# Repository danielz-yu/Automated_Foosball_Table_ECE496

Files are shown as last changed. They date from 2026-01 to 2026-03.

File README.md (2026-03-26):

# Vision-Guided Automated Foosball Opponent

**ECE496Y Capstone Design Project | University of Toronto**
<br>
**Team 2025162**

An autonomous foosball opponent system that combines real-time computer vision, mechanical actuation, and control systems to create an engaging single-player foosball experience. The system uses overhead camera tracking to detect ball position and trajectory, then controls motorized rods to intercept and kick the ball with human-competitive reaction times.

**Key Features:**
- Real-time Vision Tracking: 100 FPS global shutter camera with OpenCV-based ball and player detection
- Dual-Motor Control: Independent rotational (kick) and translational (positioning) motors per rod
- Sub-200ms Reaction Time: Faster than average human reaction time of 250ms
- Non-Permanent Installation: Removable attachment system that preserves original table

✅ **Status:** Completed!
<br>
🎯 **Target Demo:** March 25-28, 2026
<br>
💵 **Budget:** [~$2.5k](https://github.com/danielz-yu/Automated_Foosball_Table_ECE496/blob/main/deliverables/Budget%20Estimate%20%7C%20Team%202025162.pdf)
<br>
🗓️ **Timeline:** Sept. 2025 - Mar. 2026

<div align="center">
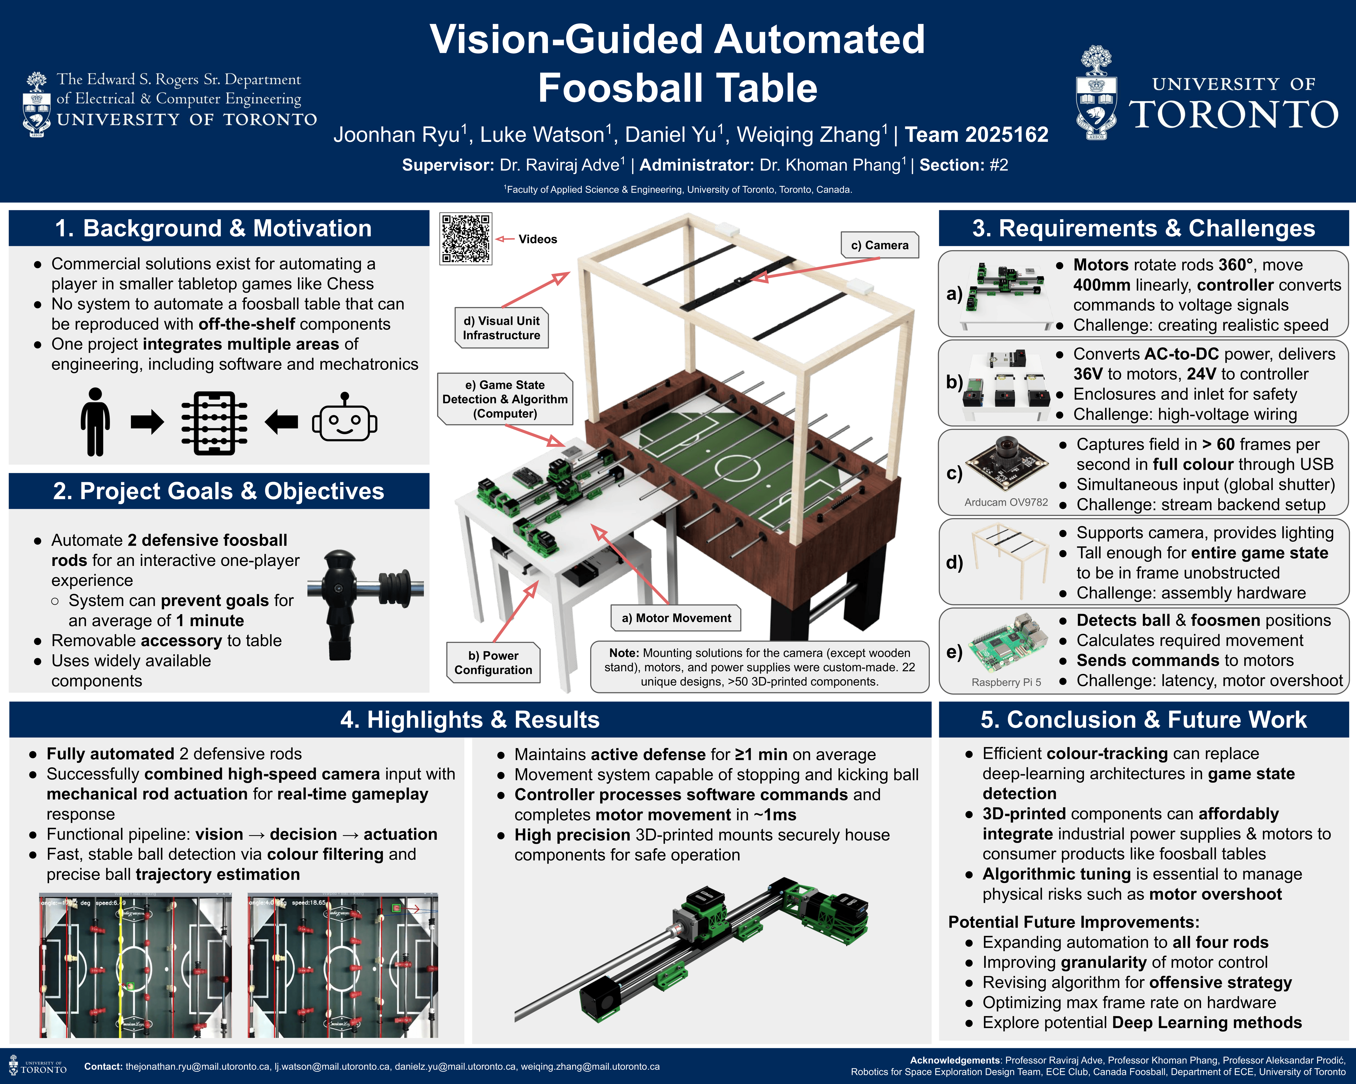
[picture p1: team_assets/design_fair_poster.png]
Design Fair Poster
    
</div>

<br>

<div align="center">
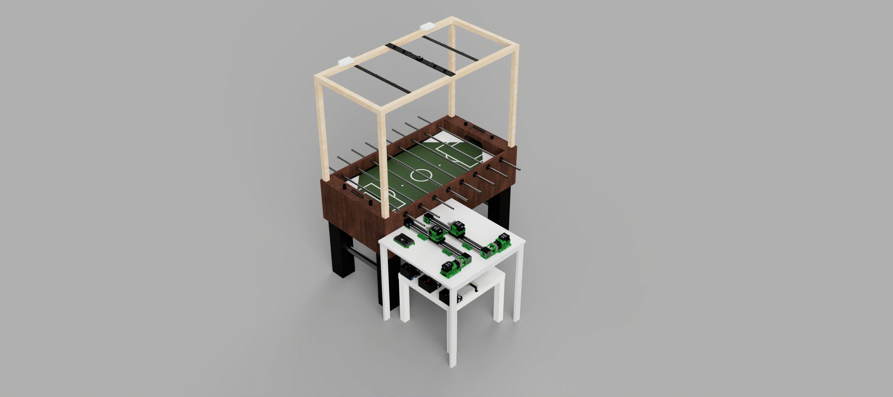
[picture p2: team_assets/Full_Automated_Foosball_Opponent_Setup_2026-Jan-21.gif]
Full Automated Foosball Table Gif (Jan. 2026)
    
</div>

## 🎯 Project Goals
- Develop defensive gameplay capable of defending for 1+ minute against untrained players
- Achieve ball control at speeds up to 1 m/s
- Demonstrate practical integration of ECE concepts: computer vision, embedded systems, control theory, and mechatronics
- Create a reproducible design for future educational use

## 🏗️ System Architecture
**Vision System:**
- Camera: ArduCam OV9782 (100 FPS, global shutter, USB interface)
- Processing: Raspberry Pi 5 (16GB RAM)
- Mounting: Custom wooden stand with 3D-printed camera holder

**Mechatronics:**
- Rotational Motors: NEMA 23 Integrated Easy Servo (90W, 3000 RPM, 0.3 Nm)
- Translational Motors: NEMA 23 Integrated Easy Servo (180W, 3000 RPM, 0.6 Nm)
- Linear Actuators: HPVB45 Belt-driven system (400mm travel)
- Controller: Teknic ClearCore motor controller
- Custom Parts: 3D-printed couplers, mounts, and brackets

**Power Distribution:**
- Translational Servos: 2× MEAN WELL LRS-350-36
- Rotational Servos: 1× MEAN WELL LRS-600-36
- Controller: MEAN WELL LRS-350-24
- Raspberry Pi: 27W USB-C adapter

**Software Stack:**
- Language: Python 3.12
- Vision Processing: OpenCV (colour filtering, ArUco marker detection)
- Control: Teknic ClearCore API
- Communication: USB serial (Raspberry Pi ↔ ClearCore)

## 👥 Team Members
**Students:**
- Joonhan Ryu
- Luke Watson
- Daniel Yu
- Weiqing Zhang

**Supervisor:** Dr. Raviraj Adve
<br>
**Administrator:** Dr. Khoman Phang

## 📄 License
This project is developed as part of ECE496 at the University of Toronto. The design is open-source for educational purposes.

## 🙏 Acknowledgments
- Professor Adve, Professor Phang, Professor Prodić
- The Edward S. Rogers Sr. Department of Electrical & Computer Engineering, University of Toronto
- Robotics for Space Exploration Design Team
- ECE Club
- Canada Foosball

#
<div align="center">
    <a href="https://www.ece.utoronto.ca/">
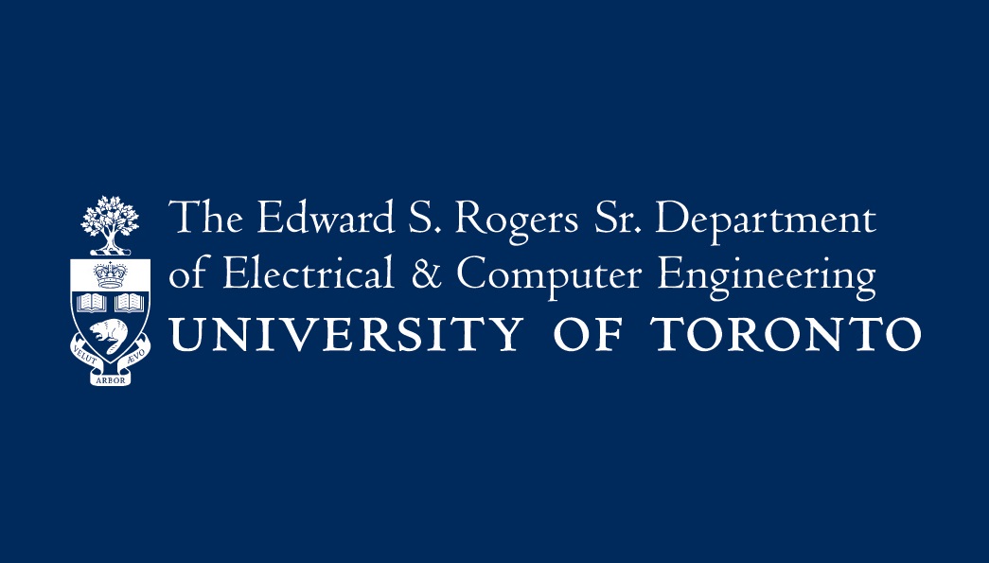
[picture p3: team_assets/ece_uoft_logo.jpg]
UofT ECE Logo
        
    </a>
</div>

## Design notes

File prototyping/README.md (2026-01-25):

# Prototyping Folder
This prototyping folder is used for initial prototyping of our ECE496 capstone project split into the Project Proposal and Project Design phases.

# Ball Tracking Software Environment Setup
1. Ensure your Python version is set to 3.12 (other versions have not been tested but it may work just the same).
2. `python -m venv <insert name of venv here>`
3. `.\<name of venv>\Scripts\Activate.ps1` if you are using PowerShell.
4. `pip install numpy==2.3.0 opencv-python==4.11.0.86`

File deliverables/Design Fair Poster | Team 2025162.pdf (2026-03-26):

- Efficient colour-tracking can replace deep-learning architectures in game state detection
- 3D-printed components can affordably integrate industrial power supplies & motors to consumer products like foosball tables
- Algorithmic tuning is essential to manage physical risks such as motor overshoot

Potential Future Improvements:
- Expanding automation to all four rods
- Improving granularity of motor control
- Revising algorithm for offensive strategy
- Optimizing max frame rate on hardware
- Explore potential Deep Learning methods

# Vision-Guided Automated Foosball Table

### Joonhan Ryu¹ , Luke Watson

1

### , Daniel Yu

1

### , Weiqing Zhang

1

### | Team 2025162

1Faculty of Applied Science & Engineering, University of Toronto, Toronto, Canada.

Supervisor: Dr. Raviraj Adve

1
| Administrator: Dr. Khoman Phang

1
| Section: #2

## 1. Background & Motivation

## 2. Project Goals & Objectives

## 3. Requirements & Challenges

4. Highlights & Results | 5. Conclusion & Future Work

a)

- Commercial solutions exist for automating a player in smaller tabletop games like Chess
- No system to automate a foosball table that can be reproduced with off-the-shelf components
- One project integrates multiple areas of engineering, including software and mechatronics
b) Power
Configuration
c) Camera
d) Visual Unit
Infrastructure
e) Game State
Detection & Algorithm
(Computer)

Acknowledgements: Professor Raviraj Adve, Professor Khoman Phang, Professor Aleksandar Prodić, Robotics for Space Exploration Design Team, ECE Club, Canada Foosball, Department of ECE, University of Toronto

Videos

b)

a) Motor Movement
- Captures field in > 60 frames per second in full colour through USB
- Simultaneous input (global shutter)
- Challenge: stream backend setup
- Supports camera, provides lighting
- Tall enough for entire game state to be in frame unobstructed
- Challenge: assembly hardware
- Detects ball & foosmen positions
- Calculates required movement
- Sends commands to motors
- Challenge: latency, motor overshoot

Note: Mounting solutions for the camera (except wooden stand), motors, and power supplies were custom-made. 22 unique designs, >50 3D-printed components.

- Automate 2 defensive foosball rods for an interactive one-player experience
- System can prevent goals for an average of 1 minute
- Removable accessory to table
- Uses widely available
components
- Fully automated 2 defensive rods
- Successfully combined high-speed camera input with mechanical rod actuation for real-time gameplay response
- Functional pipeline: vision → decision → actuation
- Fast, stable ball detection via colour filtering and precise ball trajectory estimation

c)

d)

e)

- Maintains active defense for ≥1 min on average
- Movement system capable of stopping and kicking ball
- Controller processes software commands and completes motor movement in ~1ms
- High precision 3D-printed mounts securely house components for safe operation
- Motors rotate rods 360°, move 400mm linearly, controller converts commands to voltage signals
- Challenge: creating realistic speed

Raspberry Pi 5

Arducam OV9782

- Converts AC-to-DC power, delivers 36V to motors, 24V to controller
- Enclosures and inlet for safety
- Challenge: high-voltage wiring

Contact: thejonathan.ryu@mail.utoronto.ca, lj.watson@mail.utoronto.ca, danielz.yu@mail.utoronto.ca, weiqing.zhang@mail.utoronto.ca

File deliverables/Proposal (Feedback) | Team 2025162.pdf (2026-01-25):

### UNIVERSITY OF TORONTO

ECE496 CAPSTONE PROPOSAL

TEAM 2025162, SECTION 2

# Vision-Guided Automated Foosball Opponent

Authors

Joonhan Ryu
thejonathan.ryu@mail.utoronto.ca

Luke Watson
lj.watson@mail.utoronto.ca

Daniel Yu
danielz.yu@mail.utoronto.ca

Weiqing Zhang
weiqing.zhang@mail.utoronto.ca

Supervisor

Dr. Raviraj ADVE

Administrator

Dr. Khoman PHANG

October 1st, 2025

## Executive Summary

This project seeks to develop a vision-guided automatic foosball opponent, combining real-time computerized game state tracking and mechanical actuation of rods.

It will involve multiple concepts of Electrical and Computer Engineering, providing a diverse coverage of key concepts learned by the team throughout their undergraduate education. It is important in practice as computerized opponents in other popular games such as chess or go have gained recognition, but a game with a mechanical side such as foosball has not yet been implemented in a reproducible way with off-the-shelf components and techniques.

The final product will be a removable attachment to a full-size foosball table (standard table dimensions used in professional foosball competitions) which can perform defensive gameplay for at least two rods for one side, with a reaction time around 0.2 seconds; however, effective offensive gameplay is in additional plans if the above objectives are completed.

For effective tracking, a combination of simple computer vision techniques such as color filtering or edge detection, taking full advantage of available visual input devices able to take fully synchronized frames at above 60 FPS while allowing calculation to keep up with framerate, will be used. A universal interface will allow viewing of game state and visually represented calculations while in implementation different hardware will be used to focus on control only. Off-the-shelf motors under $500 for each member of the team providing at least 1.158Nm of torque and 1000RPM of speed will ensure realistic reactions in gameplay, with one set for rotational movement and another for translational movement of the rods.

This project seeks to transform this recreational activity to a demonstration of Electrical and Computer Engineering concepts and allow players of all calibre to engage and practice in an effective single-player mode, gathering interest in both the engineering and the game.

## Contents

## 1.0 Introduction

Foosball has long been a popular tabletop game enjoyed around the world in family homes, offices, recreational centres, and professional settings. The appeal lies in its fast-paced simulated soccer gameplay and its unique blend of strategy with luck. Traditionally, this tabletop game has always been played between humans, with the winner determined on the basis of their reflexes, positioning, and ball control. However, with the evolution of intelligent robotic systems, it has become increasingly feasible to bring autonomy into various highly interactive games such as foosball.

Autonomous opponents in the game of foosball would highlight multiple levels of robotics research challenges, including but not limited to decision-making, visual perception of fast-moving objects, and prediction-based actuation. Additionally, the development of an automated foosball opponent serves both educational and research value as a fully integrated control system with the foosball table would demonstrate applied robotics concepts in real time; furthering the field of human-machine interfaces and interactive robotics.

## 2.0 Background and Motivation

Foosball is a tabletop game in which two or more players simulate soccer by controlling small plastic players mounted on metal rods, able to move in a linear and rotational fashion. It joins the ranks of other casual activities, such as darts and chess, with similar opportunity for competitive progression. In recent years, this category of games has seen a trend of projects that re-imagine how they can be played using technology. For example, a viral video by Mark Rober demonstrates a dart board that automatically moves to intercept the player’s dart through robotics and real-time tracking [1]. Foosball is an ideal candidate for this kind of experiment: its base functions are simple and accessible, yet the challenge of automation involves an interesting mix of hardware and software development, ultimately resulting in an engaging platform to demonstrate concepts in engineering.

There exists some commercial products which focus on automation of games, such as Chessnut, a chessboard that moves the pieces by itself. However, for larger scale games such projects are usually limited to student projects or hobbyists due to their size. Foosball automation is a concept that has been explored to a limited extent, mostly in post-secondary settings. Some studies have focused on individual aspects of the system, such as a paper from Eindhoven University that discusses methods of ball tracking in a ”semi-automated foosball table” [2]. A few more complete projects have been produced by student groups over the years, including one from California Polytechnic University, in which a system with full movement for four rods was built [3]. Each has their own strengths and limitations. For example, this group was able to implement a sophisticated mechanical setup but was unable to finish a working vision system. Projects seem to fall into two categories: a lack of proper funding results in an underpowered system, or the use of expensive sponsored components results in a successful system limited in its reproducibility. Our project aims to be built from scratch using entirely off-the-shelf components, while achieving a system that performs well and is easily replicated.

The main reason we chose this project is because it presents an opportunity to build something practical that integrates skills from multiple fields of Electrical and Computer Engineering in a unified system. Automation of a football table requires knowledge of power, embedded systems, real-time communication, computer vision, and algorithm design. The design process will involve the development of these individual components as well as how they interface together. Ideally, other students will also be able to interact with our design, and future groups can take inspiration from and build on our accessible implementation process, lowering the barrier to entry in terms of funding and complexity. Ultimately, this project highlights how familiar games can platform educational concepts and engineering tools.

## 3.0 Problem Statement

Traditional foosball tables rely entirely on human players to control the rods and react to the ball’s movement. While foosball is a popular recreational activity, current tables offer no digital aspect, let alone an automated opponent that can match human reaction times and conduct strategic play, and may also be difficult for beginners to get into the game, caused by the differences in player skill levels. This limits the ability to use foosball as a platform for exploring human-machine interaction and also forces foosball to an often unbalanced two-people play.

Therefore, there is a need for a vision-guided foosball opponent that integrates real-time ball tracking and mechanical actuation of rods. Such a system would not only provide an engaging opponent for casual play, but also provide a unique opportunity to showcase engineering skills, including computer vision, embedded systems, and software-hardware integration, in a recreational setting that is both accessible and engaging to a wide audience.

To achieve this, we will start working on the control of two rods that can coordinate with each other, potentially implementing all four rods on a standard sized foosball table. The development will be divided into four subsystems: the visual unit, calculation unit, control unit, and the power unit, with each team member primarily responsible for one area.

## 4.0 Project Goal

The goal of this project is to develop a control system that automates one side of a foosball table’s rods, allowing for primarily reactive but potentially active play, controlling the ball at upwards of 1m/s and defending up to one minute of continuous play.

## 5.0 System Requirements Specification

### 5.1 Vision and Strategy

Table 1. Requirements, constraints, and objectives of the vision/strategy portion.
ID | Specification | Description
1 | Input device framerate > 60 FPS. | Objective: Higher is better.
2 | Input device must detect in full color. | Requirement: For more effective detection of objects by color.
3 | Calculation of required rod movement including lateral position and kick trigger for all 1 motorized rods in < inputframerate seconds. | Requirement: Each frame should have its own calculation to update the rod position with the latest information.
4 | Input device must take all areas of frame simultaneously. | Requirement: Each part of the frame should be equally accurate to the time the information was processed.
5 | Software must have a visual ”debug” mode which shows detections, activations, and ball motion state. | Requirement: The automated system’s vision processing status should have a visible mode for finetuning purposes that can be switched off for optimization when running in normal use.
6 | Device must be able to detect whole ball and player positions in each frame | Requirement: Position of ball is required for defensive actions, and player positions for strategic offensive actions.
7 | Input device must not be visually obstructed on the way to the ball or the players | Requirement: Cannot see game state if game state is visually obstructed.
8 | Input device must connect using a universal interface (e.g. USB). | Constraint: Control hardware will change between simulation and action, and a common interface should be used for the software to use the same structure of input.

### 5.2 Mechatronics

Table 2. Requirements, constraints, and objectives of the mechatronics portion.
ID | Specification | Description
9 | Motor Input Power: Minimum 24VDC and 7.5A | Requirement: Power supply must meet this specification. See Appendix B for further details.
10 | Components Price: Does not exceed an investment of $500 from each group member, we must assume there will not be any re-reimbursements. | Constraint: Total cost cannot exceed this amount, therefore we will not acquire top-of-the-line components.
11 | Construction: System does not make permanent modifications to the foosball table, rather acts as an accessory that can be removed. | Objective: The table will be modified if needed.
12 | Rotational Motor Specifications: The motor must rotate at least 120 degrees, and output peak torque and speed of 1.158Nm and 1000RPM. | Requirement: This is for realistic gameplay. See Appendix C for detailed calculations.
13 | Translational Motor Specifications: The motor must support up to 2kg in translational movement, rotate 360 degrees, and output a peak torque and speed of at least 1.2Nm and 500RPM. | Requirement: This is for realistic gameplay. See Appendix D for detailed calculations.
14 | Linear Guide Rail: Minimum travel length must be at least 400mm. | Requirement: Based off our own measurements, the travel distance of the foosball rods fall under 400mm of travel distance, however, rods with shorter movements can use correspondingly shorter guide rails.
15 | Reaction Time: The reaction time of the motor together should average at 0.2s. | Objective: An average human reaction time is around 0.25s, therefore, the estimated motor reaction time needs to be faster to account for the computer processing time for our visual perception setup.
16 | Automated Rods: Two or more rods. | Objective: Setup will have 2 or more automated rods
17 | Defensive Ability: One or more minutes. | Objective: The system will be able to defend against a goal for at least one minute against an untrained player.
18 | Does Not Obstruct Human Side: No interference. | Requirement: Does not interfere with the opposing side of the foosball table or the abilities of the human to play..

Table 1 shows the systems requirements for the vision and strategy aspects of our design requirements for the foosball while Table 2 shows the systems requirements for the mechatronics side.

## 6.0 System Block Diagram

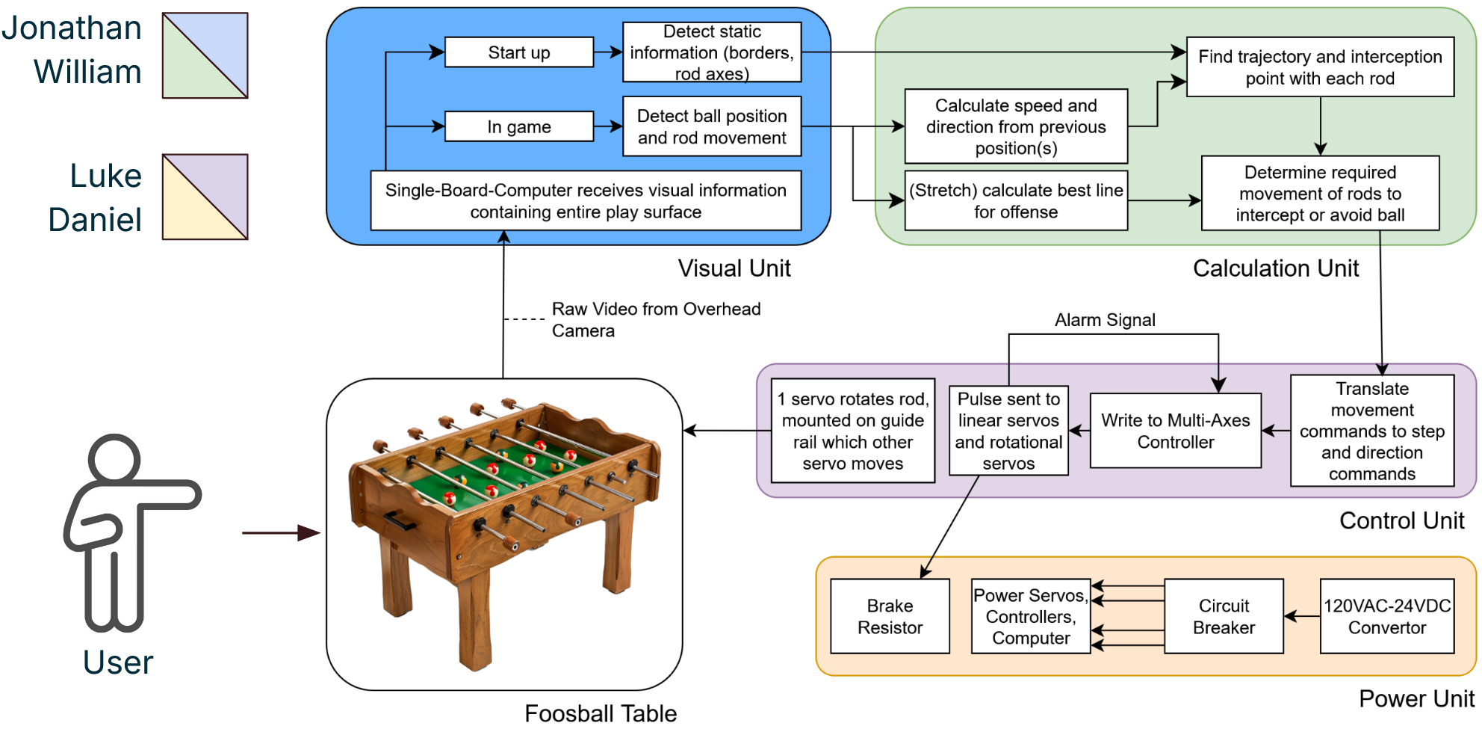
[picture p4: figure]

Figure 1. Block diagram of the automated foosball opponent system.

Figure 1 shows the overall block diagram for our system, separated into five individual units. The labels on the left denote the initial separation of responsibilities of the group members.

Starting with the foosball table, which the user interacts with on one side, an overhead video camera feeds raw footage into the Visual Unit. This unit is responsible for processing this information and generating positioning for the elements of the game, including the field boundaries, rod axes, and most importantly ball movement. This data is fed into the Calculation Unit, a micro-controller that will determine the required positioning of the automated rods to intercept the ball. Finally, the Control Unit translates this into commands output to the motors, which move and rotate the rods. Behind this flow, the Power Unit is necessary for supplying all of these different elements with sufficient power, including the motors and controller. All of these units must work together within a short time-frame to achieve real-time play.

## 7.0 Risk Assessment

Our team has identified four risks which could negatively affect the outcome of our project.

### 7.1 Uneven and Inconsistent Lighting

- During some experiments with the prototype, it was noted that edges were not as visible or colors may differ depending on lighting angle and intensity, as well as the general temperature of any light source.
- These effects may impact detection of the ball and rod, unable to either capture the full area (thus making the detected position off-center) or not capture at all, which makes accurate calculations at the desired framerate impossible.

- This is likely to happen given the variable amounts of outside sunlight and the fluctuation in artificial lighting depending on setting. To mitigate this problem, a method to evenly light the table (not affected by the shape of any light source, and thus most likely diffused) in a manner not invasive to gameplay is necessary.

### 7.2 Insufficient Accuracy of Rod Detection

- One concern about any potential methods of vision detection is that the rods may be partially or wholly undetected. The majority of cases are caused by the aforementioned lighting issue which can be mitigated, and thus this is not a major problem for the defensive case (where position of defense rods are known and there is the width of each foos-figure as a margin of error in interception).
- However, in the offensive case, the angle of attack (and the consequential line taken by the ball, in comparison with the one which minimizes interceptions) will be dramatically altered by small differences in where the ball is struck.
- While this is likely to happen, coinciding with the lighting issue, since offensive play is a stretch goal on its own, it is not highly urgent. This can be mitigated by creating backup methods of lateral rod position detection for non-motorized rods, or at the very least accurate estimates if the disparity is only a few frames long.

### 7.3 Motor Power is Insufficient

- A key component in the functionality of the automated system is the ability of the selected motors to provide enough power to rotate and move the rods so that the ball can be intercepted and kicked. The probability this will occur is low for the motors responsible for rotation, as the selected motors were above the calculated requirements. The motors guiding the linear system, however, are more at risk due to the more complex setup and weight they have to move.
- The consequence of one of the motors failing in this regard would be a limitation on the overall system to respond to a user’s inputs in a realistic way. The game would not be playable as the rods would likely miss interception, being too slow to react, or not able to kick the ball with enough force to move it.
- The root cause of this risk is both the motors themselves and our chosen setup. If either motor is too weak, it can be replaced with a more powerful version. However, this can only go so far in our goal to build an inexpensive and reproducible system. In addition, the stronger and heavier the rotational motor is the more weight the linear motor has to move. Therefore, the specifications can be modified to use a less powerful but lighter motor for rotational movement. This means kicking the ball with less force, but the system would at least be able to intercept it. Ultimately, if no combination of motors is able to both intercept the ball and deliver enough force to move it, the scope of the project must then be restricted to only gameplay in which the user plays at a slow speed. This would not be realistic gameplay, but would still allow for a demonstration of potential capabilities.

### 7.4 Processing Time is Too Slow

- Given the previous risk is not an issue and the motors can indeed react with enough speed and force, another possibility is the commands simply cannot be generated in time to feed to the motors. This involves the processing of the visual data into ideal movements to intercept the ball. We have attempted to mitigate this risk by acquiring an extremely fast computer to perform the necessary calculations in real-time. However, there is still a smaller but present chance that the latency of each different element adds up to a point where the signals are not being sent to the motors in time.
- The result of processing time being too slow is again a lack of realistic play. However, this time it is not realistic to simply replace components to improve the speed of this system.
- The scope of the prediction algorithm can be simplified to speed up processing if required. Ultimately it can be reduced to simply moving the rod to intercept the ball. Similarly to the previous risk, if there is no feasible way to achieve realistic processing time, slow gameplay can be enforced.

## 8.0 Conclusion

In summary, the development of an automated foosball opponent addresses the absence of digital and interactive features in traditional foosball tables. By integrating real-time computer vision, mechatronic controls, and software–hardware coordination, this project will transform a familiar recreational activity into an engaging platform for both entertainment and engineering demonstration, not only for advanced players, but also beginners interested in the game.

On top of a new form of recreational play, the project provides a meaningful opportunity to showcase engineering skills across software and hardware domains, including control systems, computer vision, and embedded systems. The successful completion of this project will create a final product that is both accessible to a wide audience and valuable as a showcase of engineering in a recreational field.

## Appendix

## A Gantt Chart

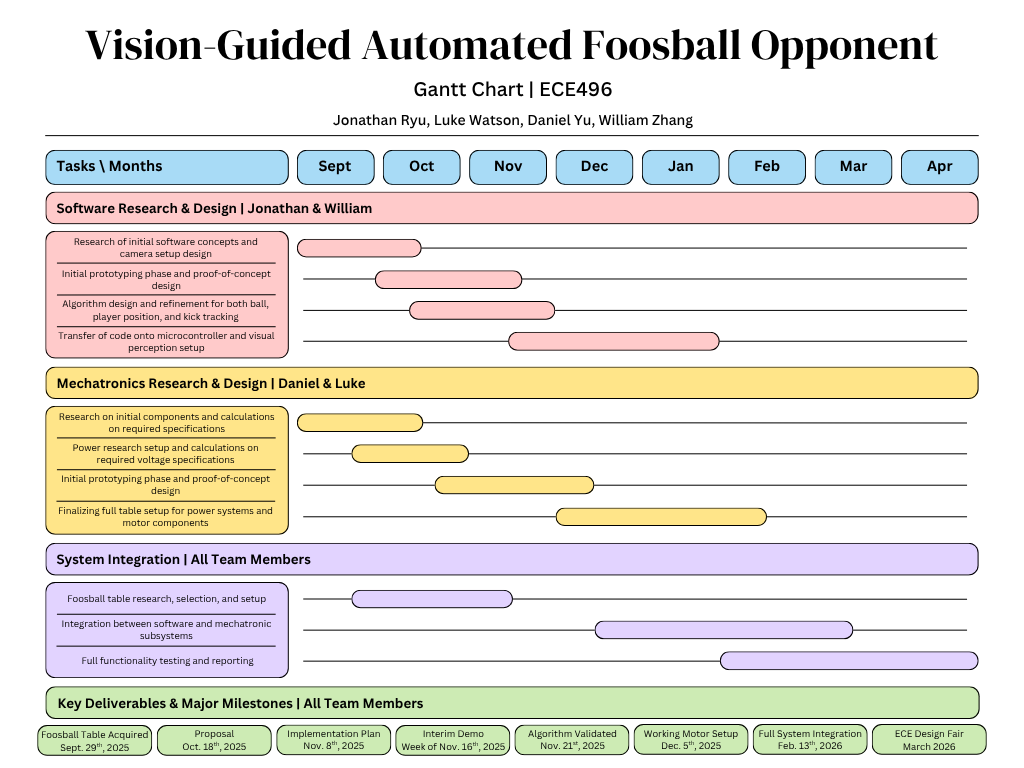
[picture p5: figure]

Figure 2. Gantt chart timeline for the 2025-2026 academic year.

Figure 2 above shows the projected timeline of tasks, key deliverables, and major milestones displayed in a Gantt chart.

## B Selected Motor Power Requirements

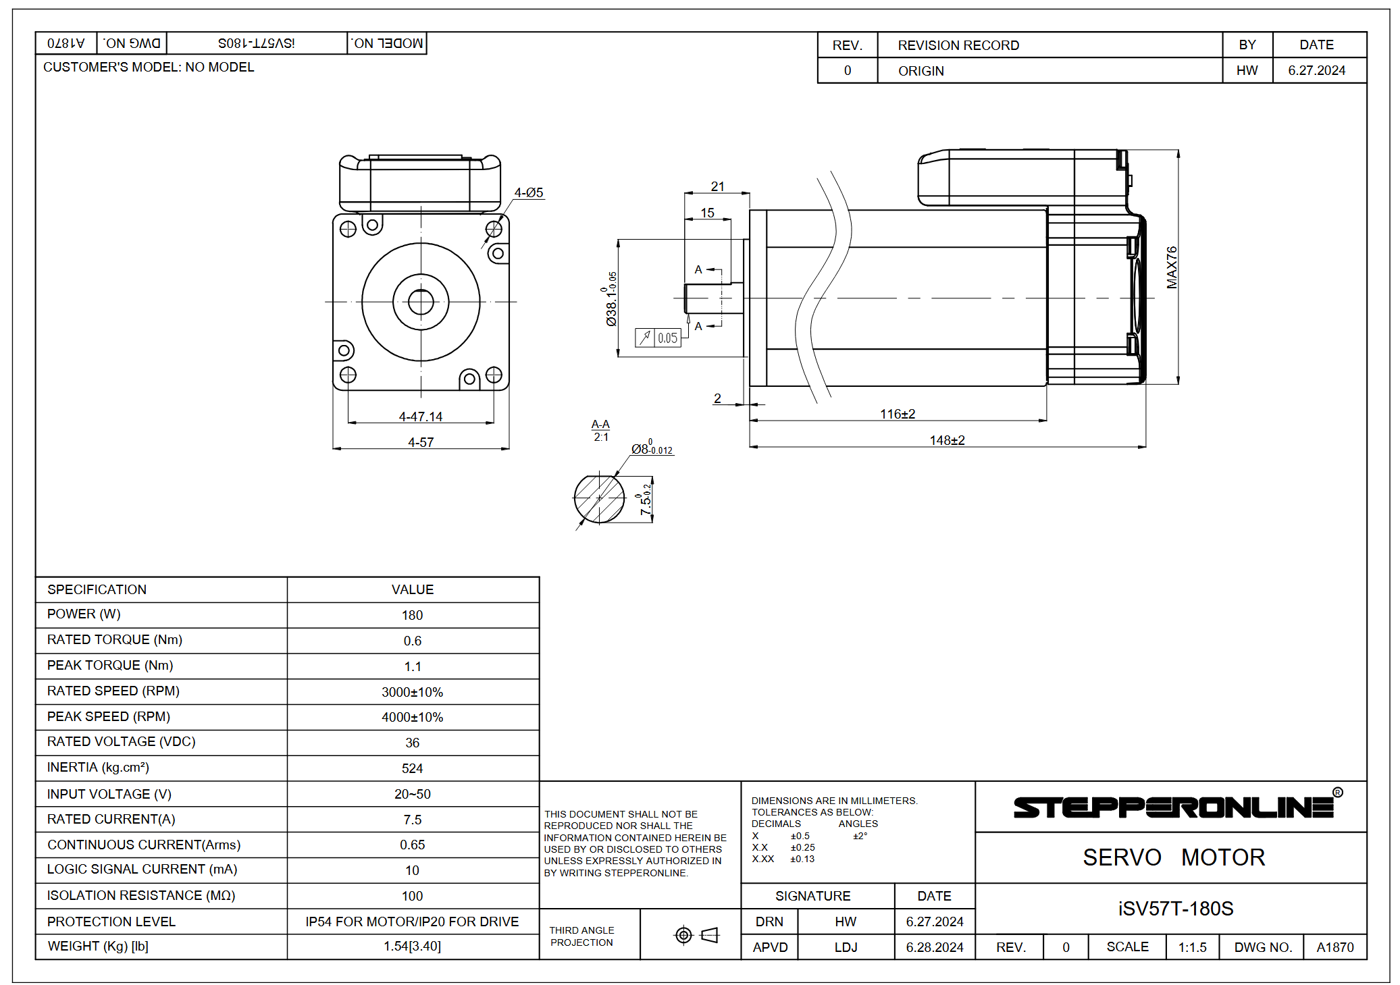
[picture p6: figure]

Figure 3. Selected motor data sheet.

## C Rotational Motor Specification Calculations

C.1 Speed

Assume the tangential speed of the foosman (attached to the rod) directly translates to the speed of the ball.

Most component specifications for speed are given in Rotations Per Minute (RPM). To derive this from speed, this formula can be used:

RPM =

ω · 60
2π

where ω is the angular velocity given by ω =

v
r

The radius in this case is the distance from the center of the rod to the foot of the foosmen, since that is the point of contact with the ball.

The height of the center of the rod from the playing field is about 3”, or 76 mm. On a professional table, the foosmen have a clearance of about 6.35 mm. In practice this value can be much higher, and since a higher clearance will give a smaller radius, and therefore larger RPM, take a higher bound of 16 mm. Therefore we can assume the radius to be approximately 60 mm. Now we can graph this equation to see what RPM will be required for desired speeds.

y =

v · 60
2π · 0.06

Thus to acheive a speed of 6m/s, around 1000 RPM is required.

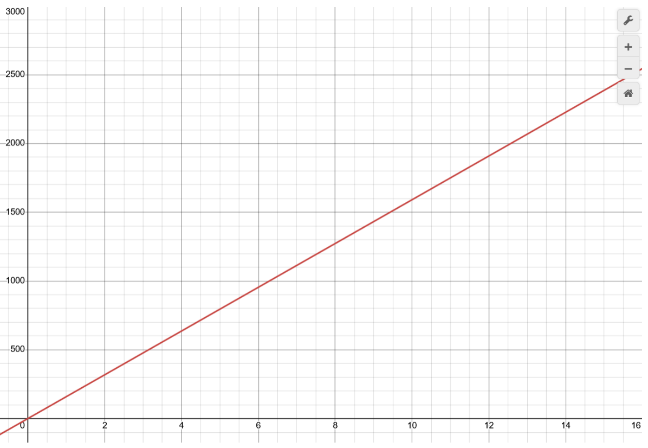
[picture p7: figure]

Figure 4. Speed to RPM.

C.2 Torque

The torque required to accelerate the rod to a desired velocity will be calculated using the formula:

τ = I · α

where I is the total inertia of the system and α is the angular acceleration.

I can be calculated as the sum of the load inertia and the motor’s rated inertia:

I = Iload + Irotor

where load inertia is the combination of inertia from the rod and from the foosmen:

Iload = Irod + If oosmen =

1
2

m · r

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
Assume the mass of the rod to be 0.7 kg¹

and the radius to be 8 mm² . This gives

Irod =

1
2

(0.7)(0.008)² = 2.24 · 10⁻⁵ kg · m

2

Since we are focusing on 2 defensive lines of play, the most foosmen a rod can have is 3, so we will use that value for N. Take a weight of 50g³
and radius of 60 mm, we get

If oosmen =

X

N

i=0

mir

2
i = N · m · r

2 = 3 · 0.05 · 0.06² = 5.4 · 10⁻⁴ kg · m

2

and subsequently

Iload = 2.24 · 10⁻⁵ + 5.4 · 10⁻⁴ = 5.625 · 10⁻⁴ kg · m

2

The reference data sheet in Appendix B shows the rotor inertia to be 524 g · cm² , giving

I = 5.265 · 10⁻⁴ + 524 · 10⁻⁷ = 5.79 · 10⁻⁴ kg · m

2

Next, to calculate angular acceleration, we first take a target speed of 6m/s and foosmen contact radius of 0.06m to calculate angular velocity:

ω =

v
r

=

6
0.06

= 100 rad/s

Time is more of a limiting factor than angle due to the fact that a servo should be able to rotate the rod a full 360 degrees, so we will use the formula

α =

ω
t

instead of α =

ω

2

2θ

Finally, with a 50ms timeframe for the motor to reach this desired speed from rest (ω0 = 0), we get

α =

ω
t

=

100
0.05

= 2000 rad/s²

Final torque is then calculated as:

τ = 5.79 · 10⁻⁴
- 2000 = 1.158 N · m

1Assuming a steel hollow rod.
2Using a typical rod with diameter of 5/8”. 3Typical weight for a non-counterbalanced foosmen.

## D Translational Motor Specification Calculations

The goal for the translational motor is to achieve realistic gameplay in a casual setting against a human opponent. We are aiming for a 1m/s translational speed with a reaction time of 0.05s⁴
. In addition, since
the translational motor needs to carry rotational motor, we can assume that it needs to carry at least 2kg of weight⁵

In order to determine the minimum required torque and speed, we first need to determine the total amount of force applied on this system using both the acceleration and force equations.

Fg = mg = 2 kg × 9.81 m
s

2 ≈ 20 N

a =

v
t

=

1

m
s
0.05 s

= 20 m
s

2

Fa = ma = 2 kg × 20 m
s

2 = 40 N

Ft = Fg + Fa = 20 N + 40 N = 60 N

From our calculations above, we need to exert at least 40 Newtons of force. To determine the corresponding peak torque and speed requirements, we can apply the torque, angular velocity, and RPM formulas below.

τ = rF sin θ = 0.02 m × 60 N = 1.2 N·m

The sine theta angle above is 90 degrees since the linear guide rail creates a constant perpendicular angle, resulting in the sine component of the torque equation to be equal to 1.

ω =

v
r

=

10 m
s
0.02 m

= 50 rad
s

The radius component in both the torque and angular velocity equations is estimated to be around 20mm from research completed on current off-the-shelf linear guide rail models.

RPM =

ω × 60
2π

=

50 × 60
2π

≈ 500RPM

Based on our calculations, the required peak torque of our motor is 1.2Nm while the speed of the motors to maintain our goal of 1m/s needs to be at least capable of 500RPM. If needed, a gearbox can be added to this system to further increase the output torque.

4Based on the same desired timeframe from standstill to full speed in Appendix C.

5
From Appendix B, the selected motor is 1.54kg in weight and so we can assume 2kg as a safe margin of error with regards to additional miscellaneous weights such as screws.

## References

[1] M. Rober. (2017, 03) Automatic bullseye, moving dartboard. Accessed: 2025-10-01. [Online]. Available: https://www.youtube.com/watch?v=MHTizZ XcUM (https://www.youtube.com/watch?v=MHTizZ_XcUM)
[2] R. Janssen, J. Best, and M. Molengraft, “Real-time ball tracking in a semi-automated foosball table,” 06 2009, pp. 128–139.
[3] J. D. Gutierrez-Franco, J. Inlow, J. Graham, and L. Huang, “Automated foosball table year 1: Final project report,” California Polytechnic State University, Tech. Rep., Dec. 2013. [Online]. Available: https://digitalcommons.calpoly.edu/mesp/196

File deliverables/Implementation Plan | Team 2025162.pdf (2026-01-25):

UNIVERSITY OF TORONTO

ECE496 IMPLEMENTATION PLAN

TEAM 2025162, SECTION 2

Vision-Guided

Automated Foosball Opponent

Authors

Joonhan Ryu

thejonathan.ryu@mail.utoronto.ca

Luke Watson

lj.watson@mail.utoronto.ca

Daniel Yu

danielz.yu@mail.utoronto.ca

Weiqing Zhang

weiqing.zhang@mail.utoronto.ca

Supervisor

Dr. Raviraj ADVE

Administrator

Dr. Khoman PHANG

November 8th, 2025

Table of Contents

### 1.0 Summary of Project Status and Changes

The following section provides an overview of the current project status and changes made since the Proposal.

### 1.1 Implementation Progress

The software side of the team is transitioning from a small prototype foosball table to a full-size one. A 100 FPS global shutter color USB camera (ArduCam OV9782 [1]) was acquired, satisfying all requirements for the input device in Section 4.1. A stand for the camera module was made to ensure the playing field is visible in the frame, 3D printed for the prototype, but built with wood for the full-size. The software now has a GUI to view detections of the game state and signals sent to the motors, and can detect the ball’s position using color filtering, extrapolating its trajectory to rod interception points. This runs on a newly acquired Raspberry Pi 5 [2] with the camera connected. On the mechatronics side, the chosen motor (StepperOnline iSV57T-180S [3]) was tested for both rotational and translational functionalities. To power them, we used a MEAN WELL LRS-350-36 [4] for which we self wired and 3D printed a custom enclosure. The translational motor was connected to a belt-driven linear actuator (HPVB45 [5]), whose carriage system had the rotational motor attached on it. The overall motor setup required custom 3D printed components which our team designed; this allowed for proper load and inertia testing on both motors, aligning with the calculations in Appendices D and E. A CAD model of our wooden stand, power supply, and motor setup can be seen in Appendix F.

### 1.2 Challenges Encountered

The software side assumed that real-time positions of the motorized rods would be available through an interface with the motors, making requirements for foosball rod position detection more lax (only the non-motorized side of the table would need this technique, and accuracy can be lower, as the purpose would be for strategy in offensive play with no effect on the motorized side’s ability to deflect the ball). However, this is no longer the case with the chosen motors. Thus, the importance of accurate color filtering (or alternative techniques) has been increased, for all directions and intensities of light. Another method to gather rotational positions of the rods (not visible to the camera) is needed. The mechatronics side found challenge in the coupler’s connection to the motor. Because the iSV57T180’s output shaft is milled in a D-shape, it did not fit snugly into the circular bore of the coupler, resulting in a loose connection. This issue required a lot of careful alignment and tightening to resolve. Overall, extensive calculations and research gave the team confidence on most hardware components, allowing the power supply and motor setups to be built smoothly.

### 1.3 Plans Ahead

After verifying existing functionalities of the software on the full-size foosball table following the installation of the camera and microcontroller, the software side plans to add lateral rod position detection functionality, improve stability in lighting of the frame, and explore solutions for detecting rotational rod position before installing motor control logic. The mechatronics side will be connecting and coding a Teknic ClearCore [6] motor controller to control all motors simultaneously. Furthermore, we plan to purchase an additional table to place the hardware components on the side of the foosball table for full assembly and proper testing purposes.

### 2.0 Possible Solutions and Design Alternatives

This section details alternative design solutions and elaborates on why they were rejected.

### 2.1 List of Considered Alternatives

Before finalizing our chosen design, three system-level alternatives were explored to evaluate different approaches to vision processing and ball tracking for the automated foosball opponent seen in Table 1.

Table 1. Considered system-level alternative designs and brief reasons for why they were rejected.
ID | Description | Reasoning for Rejection
A | Full-size desktop with a GPU paired with existing color camera using a deep-learning architecture to identify ball and/or player positions | Excessively costly and power-intensive for the intended application. FPS is very low [7] and rotational angle difficult to calculate.
B | Existing microcontroller paired with monochrome camera that uses purely edge-detection mechanisms to identify ball position and player states | Lacks robustness and computational capability. Also easily foiled by other debris that can make its way onto the table, since the camera cannot distinguish between colors.
C | Avoiding vision usage entirely and instead relying on lasers on the table or GPS sensor in ball to detect its position and accelerometers on all rods to determine position | Excessive hardware complexity, calibration challenges, and integration issues.

Alternative A proposes a full-size desktop-based system utilizing a GPU paired with a color camera and deep-learning models for visual recognition of the ball and players, offering potentially high accuracy at the expense of cost, power, and complexity. Alternative B considered a lightweight microcontroller solution using a monochrome camera and edge-detection algorithms to identify ball position, trading computational simplicity for limited robustness and adaptability to changing lighting conditions. Alternative C eliminated vision altogether by relying on external sensors—such as lasers, GPS-like tracking within the ball, and accelerometers on the rods—to determine position data, introducing considerable hardware complexity and calibration challenges. Each design explored a different trade-off between computational power, sensing accuracy, and integration complexity.

### 2.2 Elaboration and Comparison of Alternative A

Alternative A: Full-size desktop with a GPU paired with an existing color camera using a deep-learning architecture to identify ball and/or player positions.

This alternative explores the use of a desktop-class computer equipped with a discrete GPU to perform deep-learning–based vision inference. In theory, such a system could run convolutional neural networks (CNNs) or transformer-based detectors to recognize and track the foosball, players, and rods in real time.

The large compute headroom of a GPU would allow for high-resolution input and potentially robust object detection even under challenging lighting or occlusion conditions.

However, several key drawbacks make this option unsuitable for the intended design objectives. A full desktop introduces significant cost, size, and power consumption far exceeding the project’s constraints [8]. The setup would require multiple pieces of large hardware, and make the already tight setup space even less achievable. Deep-learning pipelines also demand substantial training data collection and model tuning to handle variations in table color, lighting, and camera placement—an impractical effort for a prototype-scale project [9]. We would have to adjust lighting in multiple locations, but moving the table for every scenario and occasion is impractical. Moreover, GPU-based inference produces unnecessary overhead for tracking a single small object, while increasing latency due to data transfer and preprocessing steps. These limitations reduce maintainability, portability, and reliability, making the system harder to demonstrate and deploy.

Comparison with Implemented Approach: In contrast, the implemented approach utilizes a Raspberry Pi 5 running optimized classical computer-vision algorithms such as color segmentation, thresholding, and ArUco marker detection. This design achieves real-time tracking using lightweight computation that fits within the Pi’s limited CPU resources [9]. The choice of traditional vision techniques provides fast inference without the need for model training, while the use of ArUco markers offers reliable and repeatable localization of player rods and ball position under varying lighting conditions.

Compared to Alternative A, the implemented system is:

- Far more cost-effective, requiring only a single-board computer and a low-cost camera rather than a GPU-equipped PC.
- More compact and portable, allowing the vision module to mount directly on or near the foosball table without external peripherals.
- Simpler to develop and maintain, as it relies on open-source computer-vision libraries (OpenCV) [10] and deterministic algorithms instead of complex neural-network pipelines.
- Lower power and quieter, with negligible heat generation and no need for active cooling.
- Sufficiently accurate for tracking purposes: while it may not match the theoretical precision of a trained CNN under perfect conditions, it achieves robust, consistent detection that meets gameplay and control requirements [9].
- Can run at a much higher frame rate (FPS) compared to deep-learning–based approaches, even powered under a GPU [7].

Overall, while Alternative A represents the most powerful computational option, its resource demands and engineering complexity make it over-engineered for the problem. The chosen Raspberry Pi–based vision system delivers an optimal balance of performance, cost, and simplicity, fulfilling all design requirements within practical constraints. It demonstrates that lightweight, well-tuned image-processing methods can achieve reliable real-time tracking without resorting to deep-learning hardware or training overhead.

### 3.0 Technical Design and Implementation

This section will discuss the entire design plan, at a high-level and further broken down into sub-modules.

### 3.1 System-Level Overview

The overall goal of the design is to transform a video feed of the foosball playing field into the movement of two rods that intercepts an incoming ball. The process flow begins with a camera positioned overhead the table to record a bird’s-eye-view of the table. The camera feed is then processed through a Raspberry Pi 5 Single Board Computer (SBC). The SBC will initially gauge the boundaries of the table and the axes corresponding to each of the rods using the existing method of ArUco markers (”synthetic square marker composed by a wide black border and an inner binary matrix which determines its identifier (id) [11]”) for perspective transformation. Color filtering techniques in OpenCV commonly found in internet guides such as
[12] are used to acquire ball and foosmen positions, through which the trajectory of the ball is calculated and points of interception are found on the rods, which then become the desired linear position for each of the rods. A stretch goal will involve a novel algorithm to calculate the angle of attack to line the ball through empty spaces of the opponent’s foosmen.

Once the rotational angle and the linear position for each of the two rods is known, the motors will be commanded to spin to meet these targets. For each rod, one motor controls a linear guide rail, using the motor’s rotation to move a platform across a belt. This platform holds the other motor, which rotates the rod through a direct attachment. The motors used are contained within integrated servos, housing a driver controlled through voltage pulses. The Teknic ClearCore will be used to manage the direct signal control, allowing use of its API to program the servos [6]. This was chosen for its speed and reliability as opposed to a microcontroller, which would also be more prone to errors in programming the timing. The SBC, motors, and controller are all powered through connection to an AC outlet. Distance is not an issue, however, as an extension cord with 6 outlets will be used to connect each power supply individually. Except for the SBC, the components use switching power supplies configured for individual DC voltage requirements.

### 3.2 System Block Diagram

Figure 1 visually illustrates the system’s modules and connections, in addition to the separation of tasks. Note that the diagram and the following explanations assume a system with 1 rod actuated. If funding can be acquired for a 2nd rod, the control unit will essentially be duplicated.

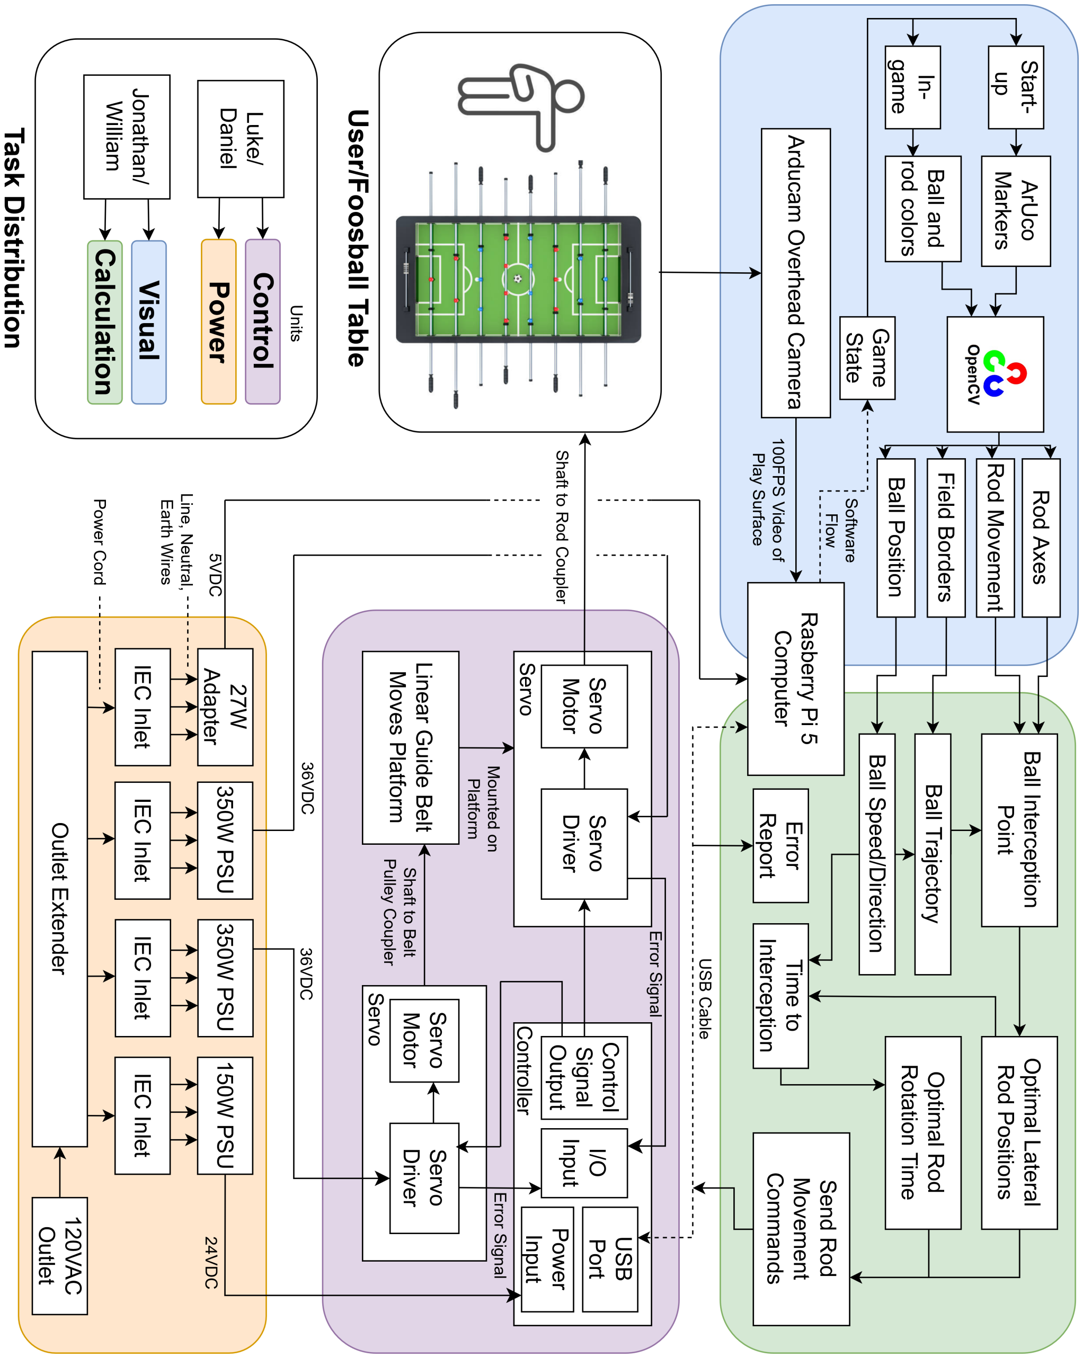
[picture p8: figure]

Figure 1. System block diagram.

### 3.3 Module Descriptions

This subsection explains the role of each connection and unit from our system block diagram.

### 3.3.1 Input/Output

The user interacts with one side of the foosball table, which has no modifications to it. The other side of the table is connected to our system and provides the rod(s) with movement response for the user to interact with.

### 3.3.2 Visual Unit

The Arducam overhead camera, after taking in a frame of the whole playing surface, sends in the frame to a Raspberry Pi 5 computer, which, on startup, detects ArUco markers on the table through the OpenCV library to gain information about the axes of the rods and border of the playing field. In game, the detection is instead for the colors of the ball and of the markers on the rods, also through OpenCV, to calculate information on the ball’s position and rods’ translational movements. This information is handed to the Calculation Unit.

### 3.3.3 Calculation Unit

Changes in the ball’s position are tracked to acquire its speed and direction, which is then extrapolated, including bounces off the playing field’s borders, then combined with rod axes locations to find interception points and thus the optimal lateral positions for each rod. Any lateral movements required to reach the positions are requested. The time taken for the ball to reach interception is also calculated using the current speed on the length of the trajectory. If that time is within the optimal rod rotation time, it requests a rotation (a ”kick”). Once a rod rotation or lateral movement is requested, it is first translated to a servo movement command using the ClearCore API which is then sent over a USB serial to ClearCore controller.

### 3.3.4 Control Unit

When the ClearCore controller receives a command to move a servo, it will translate that request to a voltage signal output to the servo’s driver. The driver also sends a signal back to the controller if a severe failure occurs, which when received by the SBC can terminate further commands. One servo is responsible for moving the belt on the linear guide rail through a pulley system, attached to the servo through a shaft coupler. The other servo is mounted on the belt’s carriage and directly connected to a rod through an additional coupler. This servo will rotate the rod and pull the rod with it when it moves linearly on the guide rail.

### 3.3.5 Power Unit

This section encompasses the components that deliver power to the rest of the system. There are four power supplies needed, two for the servos, one for the controller, and one for the SBC. It is indeed unnecessary to have individual power supplies for each unit, however this was found to be much cheaper as opposed to consolidating into one power supply. Aside from the 27W Adapter for the SBC, which resembles a laptop charging device, the rest are switching supplies with two delivering 36VDC for the servos and one 24VDC for the controller. These supplies have exposed terminals, so a 3D printed case has been used to allow for power cords to connect to inlets on the case, which are wired to the terminals inside.

### 4.0 Test and Verification

This section elaborates on methods to test and verify the design, for the requirements specified in Appendix A for the two major components: vision/strategy and mechatronics. Completed verifications are marked with (C).

### 4.1 Vision and Strategy

Table 2 details the testing methodology for the vision and strategy components of the design.

Table 2. SyRS of the vision/strategy component with testing methodologies.
ID | Specification | Verification Strategy
1 (C) | Input device framerate > 60 FPS. | REVIEW of DESIGN: Reference the datasheet of visual input unit for FPS. TEST: Verify input framerate through an application that repeats unprocessed frame input to the GUI.
2 (C) | Input device must detect in full color. | TEST: Using a webcam application that only repeats frame input to the GUI, confirm the camera is not monochrome.
3 | Calculation of required rod movement for all motorized rods in under inputframerate seconds. 1 | TEST: Add an FPS counter to the run script that displays with the debug mode (see requirement 5), where the ”FPS” is calculated by the times each processed frame is displayed.
4 (C) | Input device must take all areas of frame simultaneously. | REVIEW of DESIGN: Reference the datasheet of visual input unit. Confirm it has a global shutter.
5 (C) | Software must have a visual ”debug” mode which shows detections, activations, and ball motion state. | TEST: Confirm run with a flag on the run script which enables a live view of the camera feed in the GUI with overlays of required information, set by default to off.
6 | Device must be able to detect whole ball and player positions in each frame | TEST: In debug mode (see requirement 5), there must be one outline of the ball, and one outline per synchronization point for the lateral positions of each rod and foosmen.
7 (C) | Input device must not be visually obstructed on the way to the ball or the players | TEST: Once visual input unit and controller is installed on the foosball table, confirm there is nothing blocking view of the playing surface through an application that only repeats the frame input to the GUI.
8 (C) | Input device must connect using a universal interface (e.g. USB). | REVIEW of DESIGN: Reference the datasheet of visual input unit and confirm it utilizes a universal interface, and demonstrate above requirements while using said interface.
19 (C) | (NEW) Height of support structure must be enough to allow for selected camera to contain entire field | TEST: Confirm the entire playing surface, including borders, is visible through an application that only repeats the frame input to the GUI.
20 | (NEW) Selected computer must be able to run the software in real-time | TEST: Confirm the software can perform all functions on the chosen SBC.

### 4.2 Mechatronics

Table 3 details the testing methodology for the control and power components of the design.

Table 3. SyRS of the mechatronics component with testing methodologies.
ID | Specification | Verification Strategy
9,22 (C) | Input Power: Minimum 24VDC/7.5A for motors, 24VDC/5A for controller/ | TEST: Measure the output of the acquired power supplies before connecting them to the motors/controller.
11,18 | Construction: System does not make permanent modifications to the foosball table and does not obstruct user side. | REVIEW OF DESIGN: Confirm whether the completed system be easily removed from the table such that the original use and structure of the table is intact, and when it is present it does not obstruct unmodified side.
12 (C) | Rotational Motor Specifications: The motor must rotate at least 120 degrees, and output peak torque and speed of 1.158Nm and 1000RPM. | TEST/REVIEW OF DESIGN: The selected motors meet these specifications and have been tested to rotate the rod.
13 (C) | Translational Motor Specifications: The motor must support up to 2kg in translational movement, rotate 360 degrees, and output a peak torque and speed of at least 1.2Nm and 500RPM. | TEST/REVIEW OF DESIGN: The selected motors meet these specifications and have been tested with the target load connected to the guide rail.
14 (C) | Linear Guide Rail: The maximum travel length is 400mm (measured internally by the team). | TEST: The selected guide rail has been tested with the selected motors to achive this travel length.
15,17 | Defensive Ability: Can defend for at least 1 minute and react in 0.2s | TEST: Time the completed system to stop an untrained player from scoring a goal for at least one minute, also measuring rod movement time using the camera.
21 (C) | Controller must have 4 outputs, each with 5V step and direction signals at 300KHz per servo requirements. | REVIEW OF DESIGN: Select component exceeds these specifications.

### 5.0 References

[1] ArduCam, OV9782 Global Shutter Color Camera Module B0385, https://core-electronics.com.au/attachments/localcontent/B0385 OV9782 Global Shutter UVC Camera Datasheet 19190316e78.pdf, (https://core-electronics.com.au/attachments/localcontent/B0385_OV9782_Global_Shutter_UVC_Camera_Datasheet_19190316e78.pdf) 12 2021.
[2] Raspberry Pi. (2025, 11) Buy a raspberry pi 5. Accessed: 2025-11-05. [Online]. Available: https://www.raspberrypi.com/products/raspberry-pi-5/
[3] StepperOnline, “Nema 23 integrated easy servo motor 180w 3000rpm 0.6nm(84.98oz.in) 20-50vdc brushless dc servo motor,” Online product page, StepperOnline, accessed: 2025-11-07. [Online]. Available: https://www.omc-stepperonline.com/nema-23-integrated-easy-servo-motor-180w-3000rpm-0-6nm-84-98oz-in-20-50vdc-brushless-dc-servo-motor-isv57t-180 (https://www.omc-stepperonline.com/nema-23-integrated-easy-servo-motor-180w-3000rpm-0-6nm-84-98oz-in-20-50vdc-brushless-dc-servo-motor-isv57t-180)
[4] MEAN WELL Enterprises Co., Ltd. (2025, 09) LRS-350 Switching Power Supply Series. Accessed: 2025-11-08. [Online]. Available: https://www.meanwell.com/webapp/product/search.aspx?prod=LRS-350 (https://www.meanwell.com/webapp/product/search.aspx?prod=LRS-350)
[5] Guangzhou Hanpose 3D Technology Co., Ltd. HPVB45 Effective Travel Stroke Length 200 mm Timing Belt Linear Slide Guide Motion Module for CNC Milling Machine. Accessed: 2025-11-08. [Online]. Available: https://www.alibaba.com/product-detail/HPVB45-Effective-Travel-Stroke-Length-200mm 62368075366.html (https://www.alibaba.com/product-detail/HPVB45-Effective-Travel-Stroke-Length-200mm_62368075366.html)
[6] Teknic, Inc., ClearCore Hardware and Wiring Manual, https://teknic.com/files/downloads/clearcore user manual.pdf, (https://teknic.com/files/downloads/clearcore_user_manual.pdf) 2 2025.
[7] D. Hagens, J. Knaup, E. H. Darmstadt, and A. Weinmann. (2024, 4) Cnn-based game state detection for a foosball table. Accessed: 2025-11-05. [Online]. Available: https://arxiv.org/html/2404.05357
[8] Statista Research Department. (2025) Desktop pcs - worldwide. Accessed: 2025-11-05. [Online]. Available: https://www.statista.com/outlook/cmo/consumer-electronics/computing/desktop-pcs/worldwide (https://www.statista.com/outlook/cmo/consumer-electronics/computing/desktop-pcs/worldwide)
[9] N. Ofir and J.-C. Nebel. (2021, 10) Classic versus deep learning approaches to address computer vision challenges. Accessed: 2025-11-08. [Online]. Available: https://arxiv.org/pdf/2101.09744
[10] G. Bradski, “The OpenCV Library,” Dr. Dobb’s J. Softw. Tools, vol. 25, 11 2000.
[11] S. Garrido and A. Panov. (2025, 11) OpenCV: Detection of ArUco Marker. Accessed: 2025-11-05. [Online]. Available: https://docs.opencv.org/4.x/d5/dae/tutorial aruco detection.html
[12] GeeksForGeeks. (2025, 8) Filter Color with OpenCV. Accessed: 2025-11-05. [Online]. Available: https://www.geeksforgeeks.org/python/filter-color-with-opencv/
[13] D. L. Woods, J. M. Wyma, E. W. Yund, T. J. Herron, and B. Reed, “Factors influencing the latency of simple reaction time,” Frontiers in Human Neuroscience, vol. 9, p. 131, 2015.

### 6.0 Appendices

Additional relevant research information and calculations are listed in their respective appendix sections below.

### 6.1 Appendix A: System Requirements Specification (SyRS)

Table 4 shows the systems requirements for the vision and strategy aspects of our design while Table 5 shows the systems requirements for the mechatronic aspects of our design.

Table 4. Requirements, constraints, and objectives of the vision/strategy portion.
ID | Specification | Description
1 | Input device framerate > 60 FPS. | Objective: Higher is better.
2 | Input device must detect in full color. | Requirement: For more effective detection of objects by color.
3 | Calculation of required rod movement including lateral position and kick trigger for all motorized rods in < inputframerate seconds. 1 | Requirement: Each frame should have its own calculation to update the rod position with the latest information.
4 | Input device must take all areas of frame simultaneously. | Requirement: Each part of the frame should be equally accurate to the time the information was processed.
5 | Software must have a visual ”debug” mode which shows detections, activations, and ball motion state. | Requirement: The automated system’s vision processing status should have a visible mode for finetuning purposes that can be switched off for optimization when running in normal use.
6 | Device must be able to detect whole ball and player positions in each frame | Requirement: Position of ball is required for defensive actions, and player positions for strategic offensive actions.
7 | Input device must not be visually obstructed on the way to the ball or the players | Requirement: Cannot see game state if game state is visually obstructed.
8 | Input device must connect using a universal interface (e.g. USB). | Constraint: Control hardware will change between simulation and action, and a common interface should be used for the software to use the same structure of input.
19 | (NEW) Height of support structure must be enough to allow for selected camera to contain entire field. | Requirement: Cannot determine game state without all portions of the playing field, including positions of the borders.
20 | (NEW) Selected computer must be able to run the software in real-time | Requirement: Cannot use a computer that is unable to run the software.

Table 5. Requirements, constraints, and objectives of the mechatronics portion.
ID | Specification | Description
9 | Motor Input Power: Minimum 24VDC and 7.5A | Requirement: Power supply must meet this specification. See Appendix G for further details.
10 | Components Price: Does not exceed an investment of $500 from each group member, we must assume there will not be any re-reimbursements. | Constraint: Total cost cannot exceed this amount, therefore we will not acquire top-of-the-line components.
11 | Construction: System does not make permanent modifications to the foosball table, rather acts as an accessory that can be removed. | Objective: The original foosball table should remain intact and usable.
12 | Rotational Motor Specifications: The motor must rotate at least 120 degrees, and output peak torque and speed of 1.158Nm and 1000RPM. | Requirement: This is for realistic gameplay. See Appendix D for detailed calculations.
13 | Translational Motor Specifications: The motor must support up to 2kg, rotate 360 degrees, and output peak torque and speed of at least 1.2Nm and 500RPM. | Requirement: This is for realistic gameplay. See Appendix E for detailed calculations.
14 | Linear Guide Rail: The maximum travel length is 400mm (measured internally by the team). | Requirement: The travel distance must be within 400mm.
15 | Reaction Time: The reaction time of the motor together should average at 0.2s. | Objective: An average human reaction time is around 0.25s [13], therefore, the estimated motor reaction time needs to be faster to account for the computer processing time for our visual perception setup.
16 | Automated Rods: Two or more rods. | Objective: Setup will have two or more automated rods
17 | Defensive Ability: One or more minutes. | Objective: The system will be able to defend against a goal for at least one minute against an untrained player.
18 | Does Not Obstruct Human Side: No interference. | Requirement: Does not interfere with the opposing side of the foosball table or the abilities of the human to play.
21 | (NEW) Controller must have at least 4 independent motor control outputs, each supporting 5V step and direction signals at 300KHz. | Requirement: Controller must meet these specifications to control selected servos [3].
22 | (NEW) Controller Input Power: Minimum 24VDC and 5A. | Requirement: Power supply for the controller must meet this specification [6].

### 6.2 Appendix B: Gantt Chart

Figure 2 on the following page shows the projected timeline of tasks, key deliverables, and major milestones displayed in a Gantt chart.

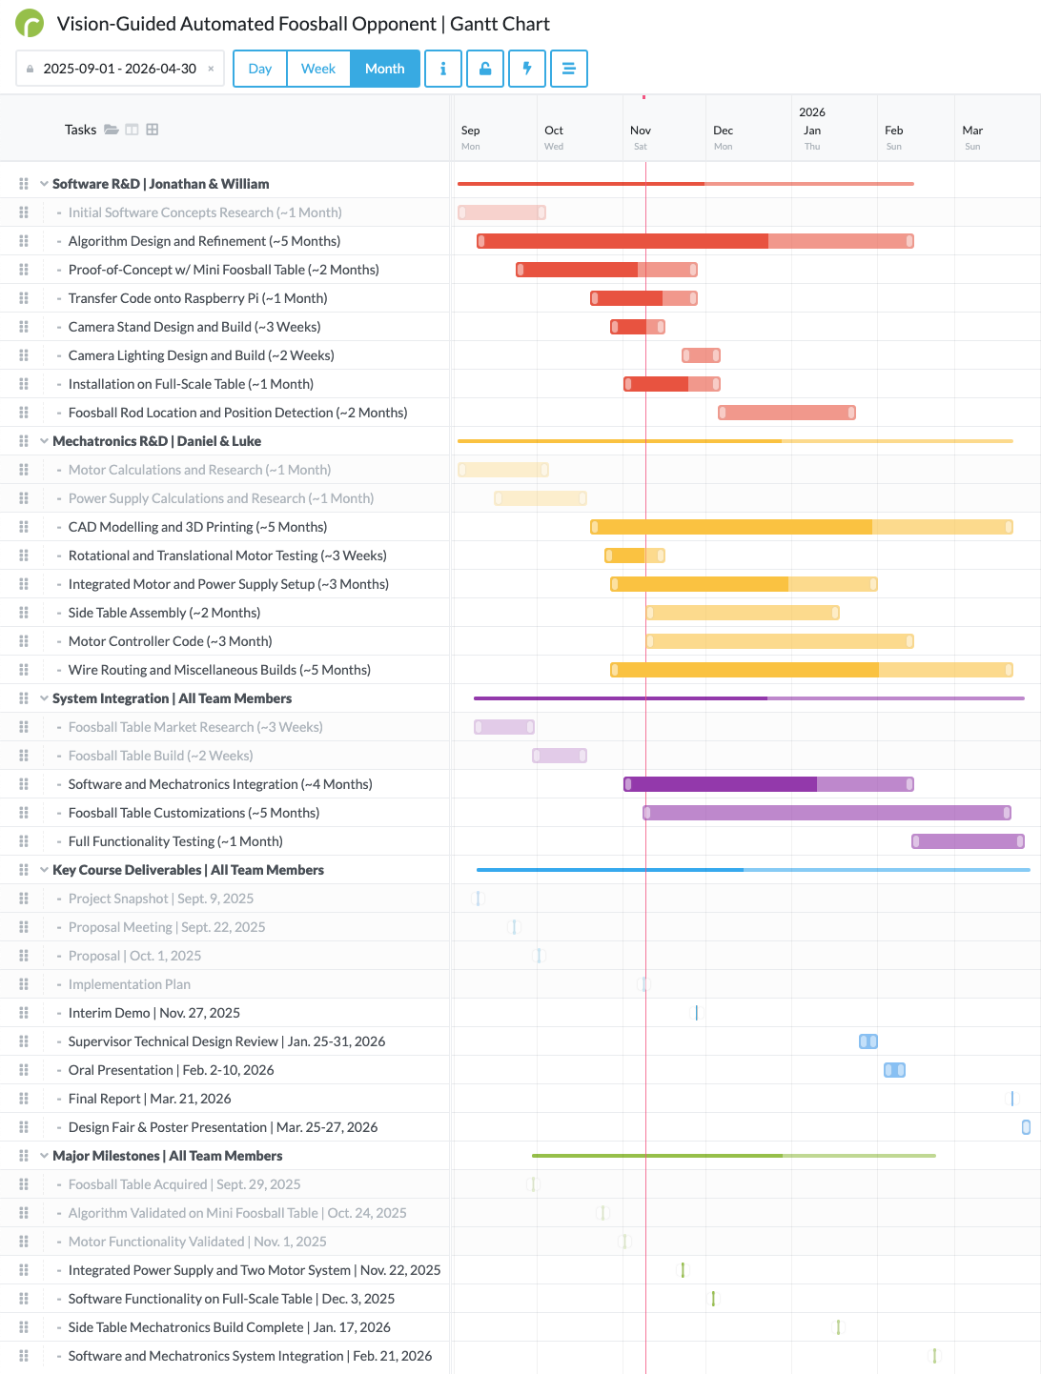
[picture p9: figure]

Figure 2. Gantt chart timeline for the 2025-2026 academic year.

### 6.3 Appendix C: Financial Plan

This appendix details the financial planning for our design and our contingency plans.

### 6.3.1 Budget Table

Tables 6-8 below details our overall budget plan for our team.

Table 6. Consumables and services budget table.
Consumables / Services | Priority | Cost / Unit | Quantity | Total Cost ($) | Requires Funding (y/n)
Balls for testing | 1 | $7.34 | 2 | $14.68 | y
Miniature foosball table (for modelling) | 1 | $36.15 | 2 | $72.30 | y
Arducam 100fps USB camera | 1 | $83.29 | 1 | $83.29 | y
3D printed custom prints and filament | 2 | $101.45 | – | $101.45 | y
Cables, connectors, and wires | 1 | – | – | $299.85 | y
L-brackets, screws, and wood | 2 | – | – | $53.71 | y
Power supplies (LRS series) | 1 | $50 | 4 | $200 | y
Raspberry Pi 5 (16GB) + cooling + PSU | 1 | $226.08 | 1 | $226.08 | y
SD card (128GB) | 2 | $19.20 | 1 | $19.20 | y
Servos (NEMA 23 Easy Servo) | 1 | $174.26 | 2 | $348.52 | y
Linear belt drive (HPVB45) | 1 | $152.58 | 4 | $610.32 | y
Teknic ClearCore Controller | 1 | $179.60 | 1 | $179.60 | y
Shipping, duties, and taxes | 2 | – | – | $89.72 | y
Base foosball table | 1 | $80.00 | 1 | $80.00 | y
IKEA Table | 2 | $60.00 | 1 | $60.00 | y
Foosball Rod | 2 | $19.99 | 2 | $39.98 | y
Total Consumables / Services | | | | $2,478.70

Table 7. Capital equipment budget table.
Capital Equipment | Priority | Cost / Unit | Quantity | Total Cost ($) | Requires Funding (y/n)
No capital equipment (all components under consumables) Total Capital Equipment | – | – | – | $0 $0 | n

Table 8. Student labour budget table.
Student Labour | Cost / Hr¹ | Hours² | Total ($)
Joonhan Ryu Luke Watson Daniel Yu Weiqing Zhang Total Student Labour (unfunded) | $42 $42 $42 $42 | 120 120 120 120 | $5,040 $5,040 $5,040 $5,040 $20,160
Total Cost of Project | $22,638.70
Total Cost Requiring Funding | $2,478.70

Funding Summary
Students ($100 each) | $400
Supervisor | $226.08
Other (sponsorships, materials reuse) | $0
Requested from ECE496 | $1,852.62
Total Funding | $2,478.70

### 6.3.2 Contingency Plan

In the event that funding is promised but delayed, the team will provide the necessary costs with the expectation of later reimbursement. In the event that funding is reduced, there are multiple scenarios depending on the amount the team is able to receive:

- Amount received is enough to cover everything except the components required for actuation of the second foosball rod.

– In this case, the team will cover the costs for the components of the second foosball rod.

- Amount received is not enough to cover the components required for the actuation of the first foosball rod.

– In this case, the team will fund the remaining components and limit the scope to one foosball rod.

- Amount received is nothing.

– In this case, the team will fund all the components for the actuation of one foosball rod and again limit the scope.

### 6.4 Appendix D: Rotational Motor Specification Calculations

This appendix section shows the calculations behind the system requirement specifications for the rotational motor’s speed and torque.

1Based on cost/hr from the provided example budget table.
2Based on the Gantt chart in Figure 2 and assuming five hours of work per team member for approximately six months (Sept., Oct. , Nov., Jan., Feb., Mar.).

### 6.4.1 Rotational Speed Calculations

Assume the tangential speed of the foosman (attached to the rod) directly translates to the speed of the ball.

Most component specifications for speed are given in rotations per minute (RPM). To derive this from speed, this formula can be used:

RPM =

ω · 60
2π

where ω is the angular velocity given by ω =

v
r

The radius in this case is the distance from the center of the rod to the foot of the foosmen, since that is the point of contact with the ball.

The height of the center of the rod from the playing field is about 3”, or 76mm. On a professional table, the foosmen have a clearance of about 6.35mm. In practice this value can be much higher, and since a higher clearance will give a smaller radius, and therefore larger RPM, take a higher bound of 16mm. Therefore we can assume the radius to be approximately 60mm. Now we can graph this equation to see what RPM will be required for desired speeds as seen in Figure 3.

y =

v · 60
2π · 0.06


Figure 3. Speed to RPM.

Thus to acheive a speed of 6m/s, around 1000RPM is required.

### 6.4.2 Rotational Torque Calculations

The torque required to accelerate the rod to a desired velocity will be calculated using the formula:

τ = I · α

where I is the total inertia of the system and α is the angular acceleration.

I can be calculated as the sum of the load inertia and the motor’s rated inertia:

I = Iload + Irotor

where load inertia is the combination of inertia from the rod and from the foosmen:

Iload = Irod + If oosmen =

1
2

m · r

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
Assume the mass of the rod to be 0.7kg³

and the radius to be 8 mm⁴ . This gives

Irod =

1
2

(0.7)(0.008)² = 2.24 · 10⁻⁵ kg · m

2

Since we are focusing on two defensive lines of play, the most foosmen a rod can have is three, so we will use that value for N. Take a weight of 50g⁵
and radius of 60mm, we get

If oosmen =

X

N

i=0

mir

2
i = N · m · r

2 = 3 · 0.05 · 0.06² = 5.4 · 10⁻⁴ kg · m

2

and subsequently

Iload = 2.24 · 10⁻⁵ + 5.4 · 10⁻⁴ = 5.625 · 10⁻⁴ kg · m

2

The reference datasheet in Appendix G shows the rotor inertia to be 524 g · cm² , giving

I = 5.265 · 10⁻⁴ + 524 · 10⁻⁷ = 5.79 · 10⁻⁴ kg · m

2

Next, to calculate angular acceleration, we first take a target speed of 6m/s and foosmen contact radius of 0.06m to calculate angular velocity:

ω =

v
r

=

6
0.06

= 100 rad/s

Time is more of a limiting factor than angle due to the fact that a servo should be able to rotate the rod a full 360 degrees, so we will use the

α =

ω
t

instead of α =

ω

2

2θ

Finally, with a 50ms timeframe for the motor to reach this desired speed from rest (ω0 = 0), we get

α =

ω
t

=

100
0.05

= 2000 rad/s²

3Assuming a steel hollow rod.
4Using a typical rod with diameter of 5/8”. 5Typical weight for a non-counterbalanced foosmen.

Final torque is then calculated as:

τ = 5.79 · 10⁻⁴
- 2000 = 1.158 N · m

### 6.5 Appendix E: Translational Motor Specification Calculations

The goal for the translational motor is to achieve realistic gameplay in a casual setting against a human opponent. We are aiming for a 1m/s translational speed with a reaction time of 0.05s⁶
. In addition, since
the translational motor needs to carry rotational motor, we can assume that it needs to carry at least 2kg of weight⁷

In order to determine the minimum required torque and speed, we first need to determine the total amount of force applied on this system using both the acceleration and force equations.

Fg = mg = 2 kg × 9.81 m
s

2 ≈ 20 N

a =

v
t

=

1

m
s
0.05 s

= 20 m
s

2

Fa = ma = 2 kg × 20 m
s

2 = 40 N

Ft = Fg + Fa = 20 N + 40 N = 60 N

From our calculations above, we need to exert at least 40 Newtons of force. To determine the corresponding peak torque and speed requirements, we can apply the torque, angular velocity, and RPM formulas below.

τ = rF sin θ = 0.02 m × 60 N = 1.2 N·m

The sine theta angle above is 90 degrees since the linear guide rail creates a constant perpendicular angle, resulting in the sine component of the torque equation to be equal to 1.

ω =

v
r

=

10 m
s
0.02 m

= 50 rad
s

The radius component in both the torque and angular velocity equations is estimated to be around 20mm from research completed on current off-the-shelf linear guide rail models.

6Based on the same desired timeframe from standstill to full speed in Appendix D.

7
From Appendix G, the selected motor is 1.54kg in weight and so we can assume 2kg as a safe margin of error with regards to additional miscellaneous weights such as screws.

RPM =

ω × 60
2π

=

50 × 60
2π

≈ 500RPM

Based on our calculations, the required peak torque of our motor is 1.2Nm while the speed of the motors to maintain our goal of 1m/s needs to be at least capable of 500RPM. If needed, a gearbox can be added to this system to further increase the output torque.

### 6.6 Appendix F: Computer-Aided Design (CAD) Models

Figure 4 shows the computer-aided design (CAD) model for the wooden camera stand and black camera holder attached directly over the foosball table.

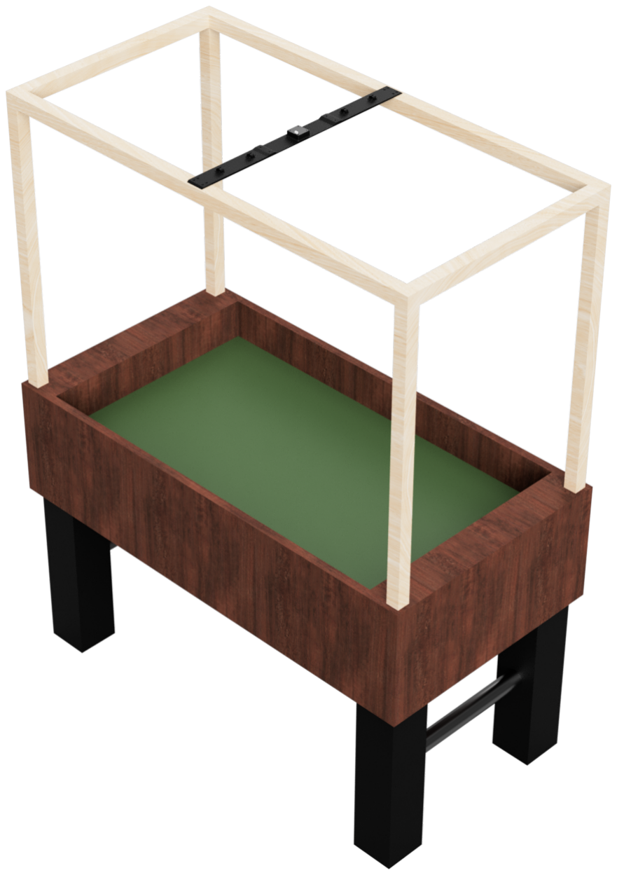
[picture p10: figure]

Figure 4. CAD model of the camera setup over the foosball table.

Figure 5 shows the CAD model of the MEAN WELL LRS-350-36 power supply unit in silver and its custom safety enclosure in black.

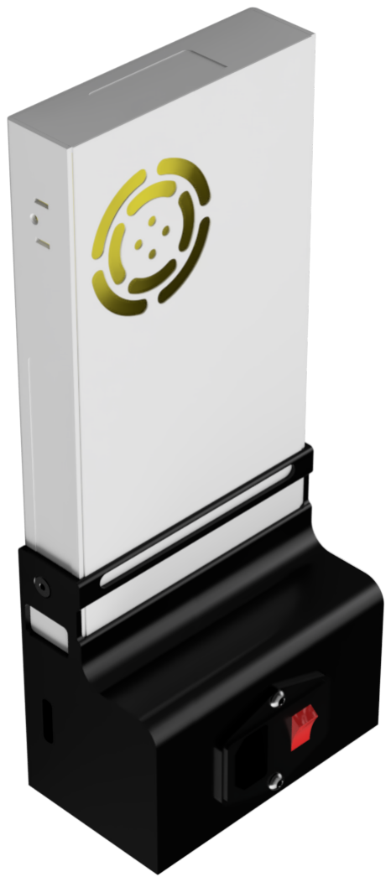
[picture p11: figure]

Figure 5. CAD model of the power supply with a custom enclosure.

Figure 6 shows the overall motor setup with the HPVB45 linear guide rail for one foosball rod. The translation motor is on the right coupled to the linear guide rail for translational movement while the rotational motor is sitting top of the carriage system. The green components are all customized 3D prints to secure the motors and the guide rail.

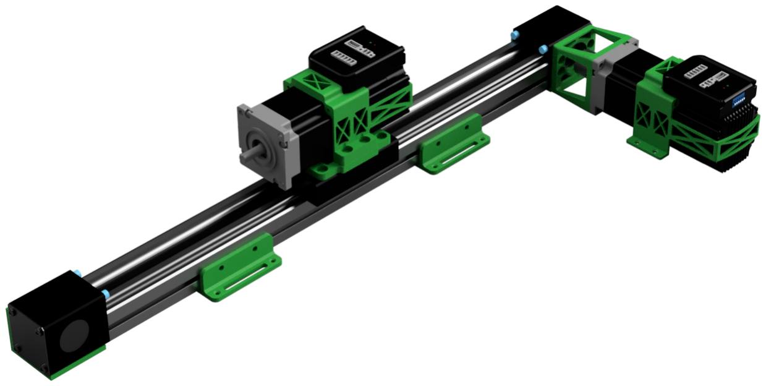
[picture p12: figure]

Figure 6. CAD model of our dual motor setup.

### 6.7 Appendix G: Servo Datasheet Reference

Figure 7 shows the specifications for the selected motor.

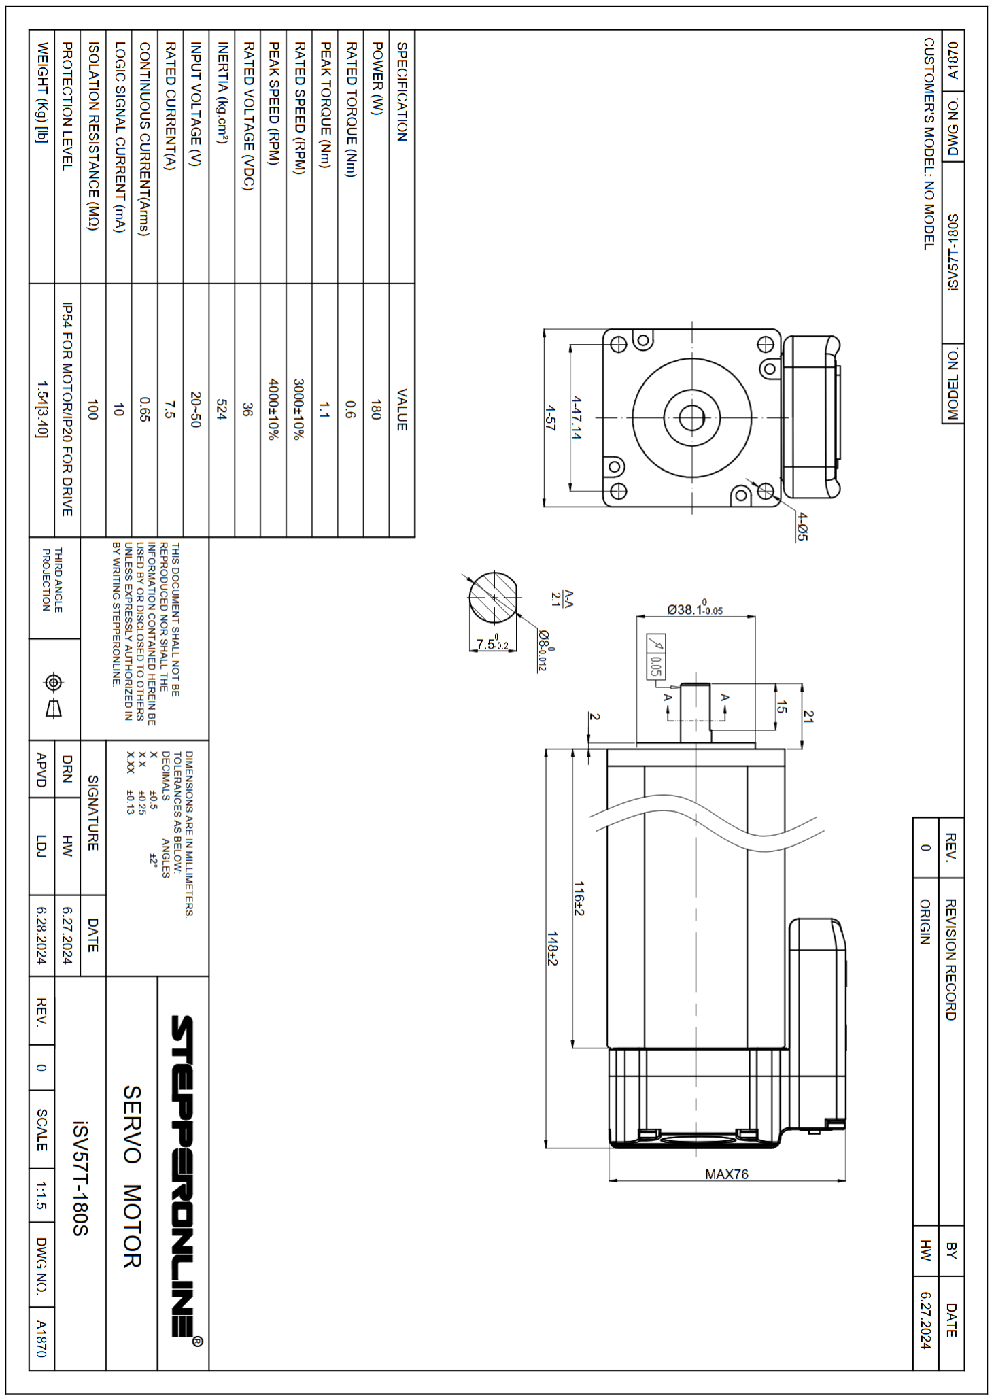
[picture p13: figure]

Figure 7. Selected motor datasheet [3].

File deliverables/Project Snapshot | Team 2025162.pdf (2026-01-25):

Project ID: 2025162

Students: Daniel Yu, Weiqing Zhang, Luke Watson, Joonhan Ryu

Supervisor: Raviraj Adve

Title: Vision-Guided Automated Foosball Opponent

Motivation: Many games have an accessible method of practice against a non-human opponent; however, foosball is a game that requires at least two players to enjoy. The ECE common room currently houses a foosball table, which students use as a break activity when studying to help refresh and de-stress. This project aims to create an automated foosball opponent that allows for solo play and independent practice while also serving as an interactive platform for students to explore concepts in computer vision, mechatronics, and real-time control.

Goal: Design and implement a foosball table extension that automates one player’s rods, allowing for primarily defensive but potentially offensive play based on the ball’s trajectory.

Brief Description: Computer vision will be used to track the position and trajectory of the ball, along with the locations of the “foosmen” (figurines on the rods of a foosball table that are used to strike the ball). Additionally, it will determine the optimal rod positions required for the automated player to intercept and play the ball. These rods will be motorized with a mechatronic setup to enable both rotational and translational movements controlled through software. This automated opponent will be designed to defend in the opposite direction, with future extensions exploring strategic plays based on the positioning of the human opponents’ “foosmen”.

Anticipated Outcome: A functional foosball table that automates one player’s movement on at least two defensive lines, reliably matching an amateur’s ability for casual play. The intention is for this automated foosball table to be placed in the ECE common room, providing all students and staff with the opportunity to enjoy with or without a friend.

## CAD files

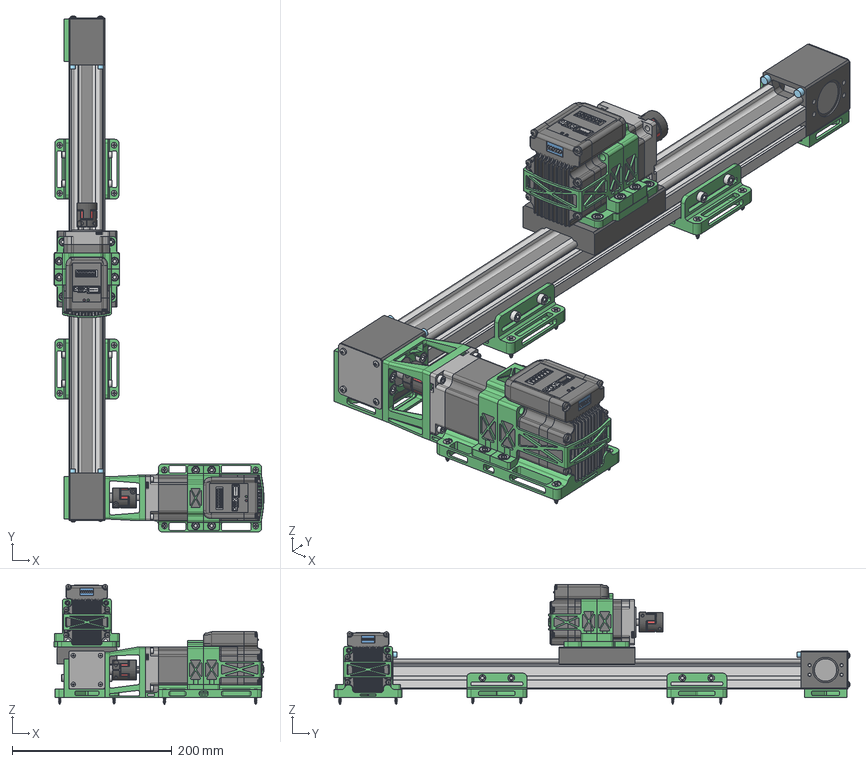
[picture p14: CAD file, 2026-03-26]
cad_files/Motor Setup/Full Motor Build (Defensemen).step
262.3 x 645.2 x 150.6 mm
¸´¼þ gb.stp^HPVB45-200 x 2
¸´¼þ lxc-305^HPVB45-200
¸´¼þ zcz.stp^HPVB45-200 x 2
¸´¼þ zc-65.stp^HPVB45-200
¸´¼þ zc-1.stp^HPVB45-200
cross recessed pan head screws gb_GB_CROSS_SCREWS_TYPE1 M3X4-4 H typ e-N x 4
cross recessed pan head screws gb_GB_CROSS_SCREWS_TYPE1 M3.5X5-5 H t ype-N x 4
Sprzęgło D25 L30.iam x 2
CT_1
QG_1
FPCB_2
CONNECTOR_3_81MM6PIN_MALE_2
CONNECTOR_3_81MMCLOSED2PIN_MALE
DPCB_1
BOMA_1
CPCB_2
LS22_2 x 6
LS10_2 x 2
LS2_5_2 x 3
front end cover
GB__T818-2000______________M3__ x 4
GB__T276-94__________6000-2Z
GB__T848-2002______A__3__0__5 x 4
PRODUCT_14681
GB__T276-94__________608-2Z
PRODUCT_22216
shaft-21
TM Front Holder
TM Back Holder
TM Foundation
91292A117_18-8 Stainless Steel Socket Head Screw x 4
92290A867_Super-Corrosion-Resistant 316 Stainless Steel Socket Head S crew x 4
91292A124_18-8 Stainless Steel Socket Head Screw x 20
91290A123_Alloy Steel Socket Head Screw x 4
LGR Coupler Bracket (Defensemen)
LGR Height Extension x 2
LGR Foundation x 2
91292A125_18-8 Stainless Steel Socket Head Screw x 8
¸´¼þ hk.stp^HPVB45-200
LGR RM Carriage Bracket (Defensemen)
LGR RM Front Holder (Defensemen)
LGR RM Back Holder (Defensemen)
CT_1_1
QG_1_1
FPCB_2_1
CONNECTOR_3_81MM6PIN_MALE_2_1
CONNECTOR_3_81MMCLOSED2PIN_MALE_1
DPCB_1_1
BOMA_1_1
CPCB_2_1
LS22_2_1 x 6
LS10_2_1 x 2
LS2_5_2_1 x 3
front end cover_1
GB__T818-2000______________M3___1 x 4
GB__T276-94__________6000-2Z_1
GB__T848-2002______A__3__0__5_1 x 4
PRODUCT_14681_1
GB__T276-94__________608-2Z_1
PRODUCT_22216_1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

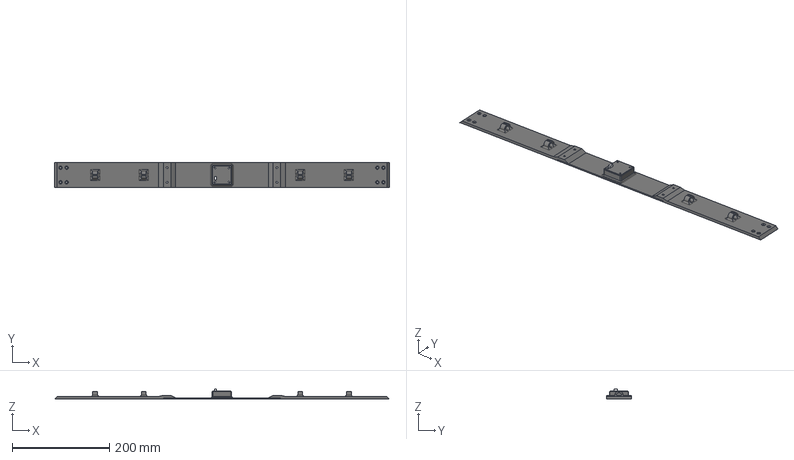
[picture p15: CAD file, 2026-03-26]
cad_files/Overhead Stand/Camera Holder/Camera Holder Assembly.step
688.3 x 50.8 x 21.6 mm
孔距18mm 总高7mm（ 3.5+3.5）塑料
镜头
Camera Holder Middle
Camera Holder Sides x 2

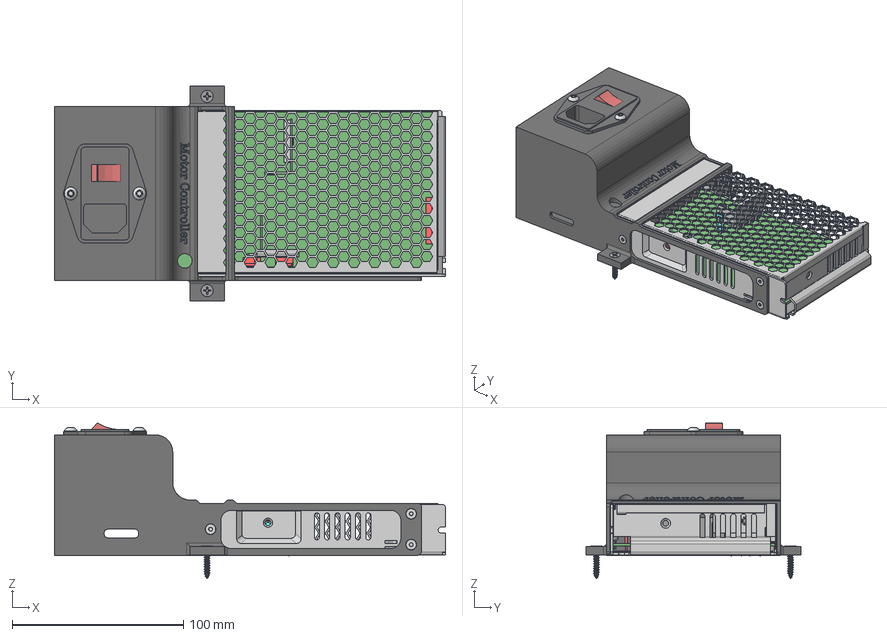
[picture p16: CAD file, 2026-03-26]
cad_files/Power Supply/Controller PSU/Controller PSU Assembly.step
228.0 x 125.3 x 90.8 mm
_X2_02CB_X0_T_X2_02CB_X0_W-3760
MOS15_5X10_1_1_1_1_1_1_1_3 x 4
_X2_4E0A84CB_X0_
DDD_1
DDD
DD
TTTT
PIN_1_1
P2
MHS033_1
TN_1_1_1_1_1
PCB
MYLAR_3-1037090
MYLAR_2-1038430
MYLAR_1-1039770
MYLAR-1047460
IEC Inlet
Controller PSU Cover
92095A194_Button Head Hex Drive Screw x 2
92125A125_18-8 Stainless Steel Hex Drive Flat Head Screw x 3

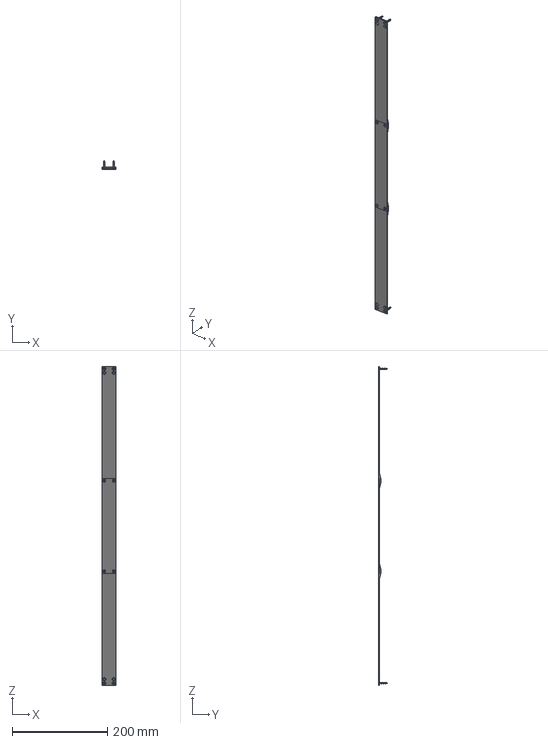
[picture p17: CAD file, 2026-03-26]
cad_files/Overhead Stand/LED Light Holder/LED Light Holder Assembly.step
30.0 x 19.1 x 670.0 mm
92125A125_18-8 Stainless Steel Hex Drive Flat Head Screw x 4

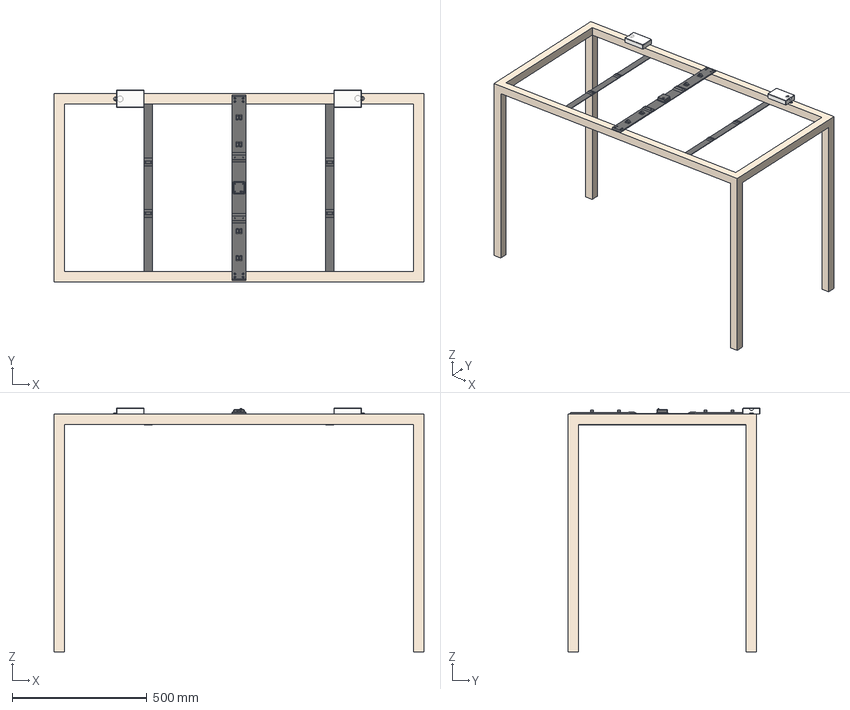
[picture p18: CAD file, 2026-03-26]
cad_files/Overhead Stand/Overhead Stand Assembly.step
1371.6 x 711.4 x 904.0 mm
Camera Stand
孔距18mm 总高7mm（ 3.5+3.5）塑料
镜头
Camera Holder Middle
Camera Holder Sides x 2
92125A125_18-8 Stainless Steel Hex Drive Flat Head Screw x 8
92125A188_18-8 Stainless Steel Hex Drive Flat Head Screw x 4

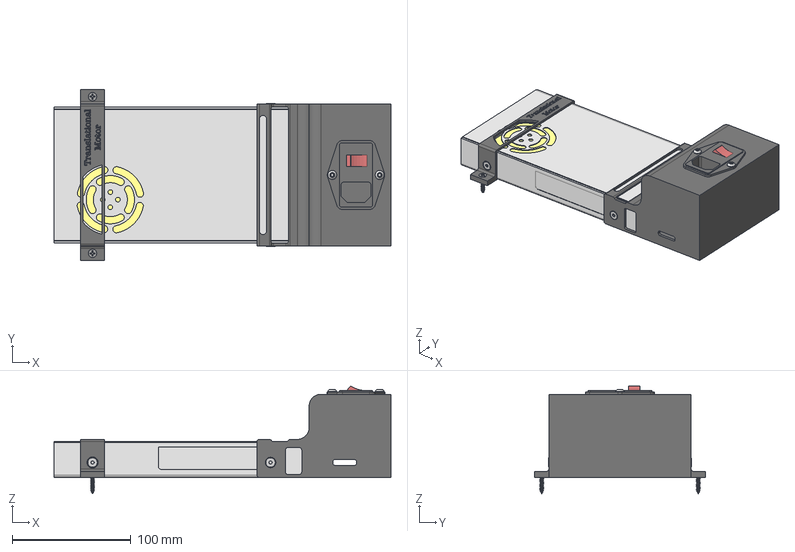
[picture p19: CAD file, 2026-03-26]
cad_files/Power Supply/Motor PSU/TM PSU Assembly.step
284.0 x 144.0 x 90.8 mm
converter_lrs-350-36
92125A188_18-8 Stainless Steel Hex Drive Flat Head Screw x 4
92095A194_Button Head Hex Drive Screw x 2
IEC Inlet
TM PSU Cover

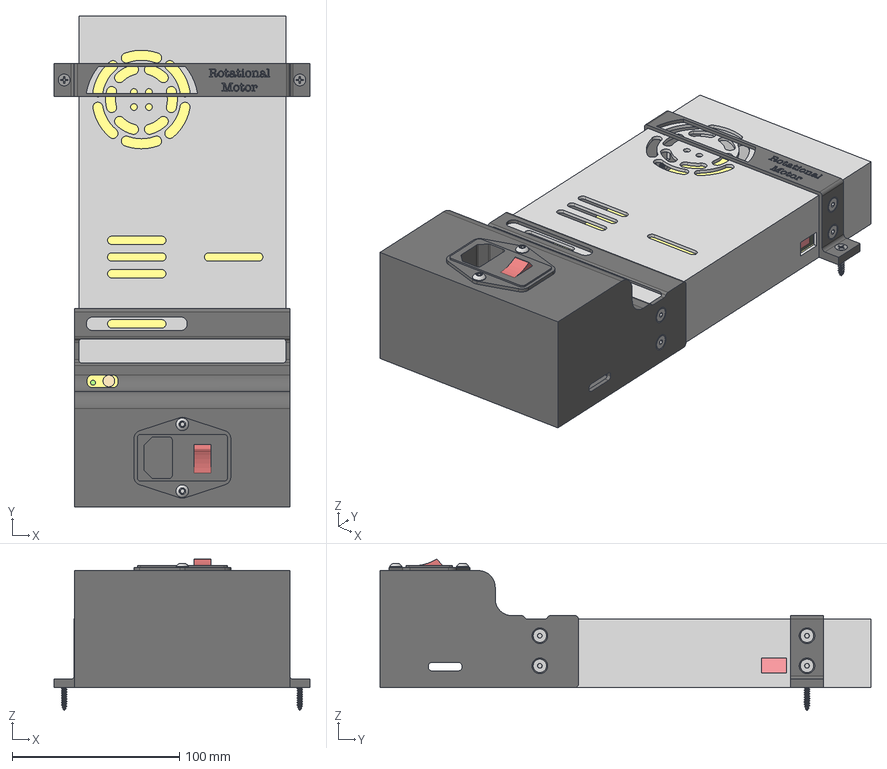
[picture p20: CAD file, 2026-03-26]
cad_files/Power Supply/Motor PSU/RM PSU Assembly.step
153.1 x 293.9 x 90.8 mm
LRS-600-36
RM PSU Cover
IEC Inlet
92095A194_Button Head Hex Drive Screw x 2
92125A188_18-8 Stainless Steel Hex Drive Flat Head Screw x 8

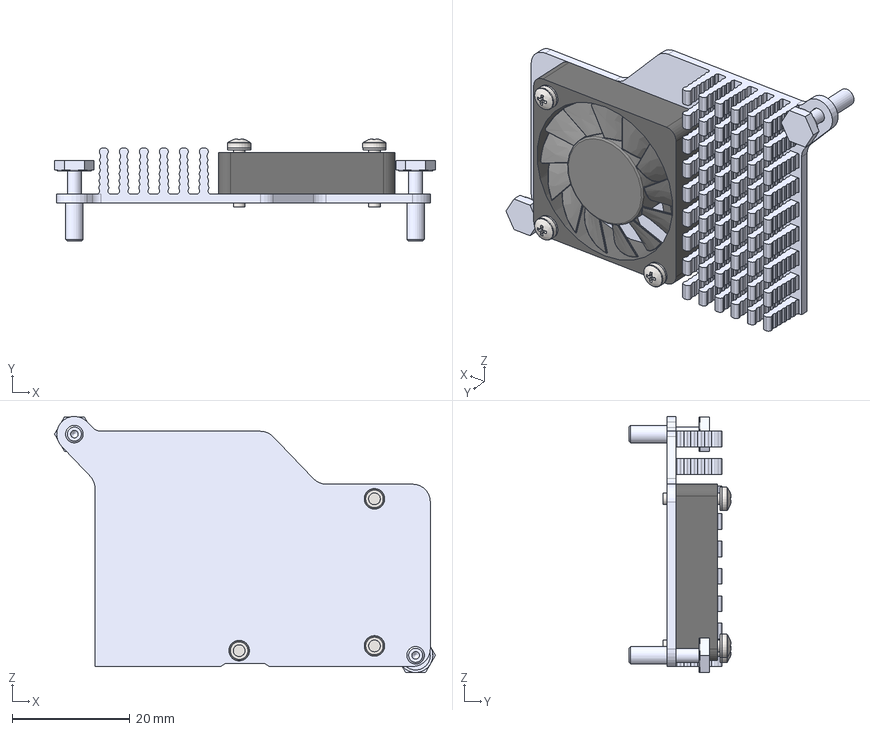
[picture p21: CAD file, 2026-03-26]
cad_files/Microcontroller/Pi Active Cooler.step
64.8 x 17.4 x 43.5 mm
Heatsink-fan-base_RPi5
RotorBlades
MotorHouse
Bolt_M3 PF
Bolt_M3 PF_1
pan head cross recess screw_din_DIN EN ISO 7045 - M2 x 10 - Z - 10N
pan head cross recess screw_din_DIN EN ISO 7045 - M2 x 10 - Z - 10N_1
pan head cross recess screw_din_DIN EN ISO 7045 - M2 x 10 - Z - 10N_2
plain washer small grade a_din_Washer DIN 433 - 2
plain washer small grade a_din_Washer DIN 433 - 2_1
plain washer small grade a_din_Washer DIN 433 - 2_2

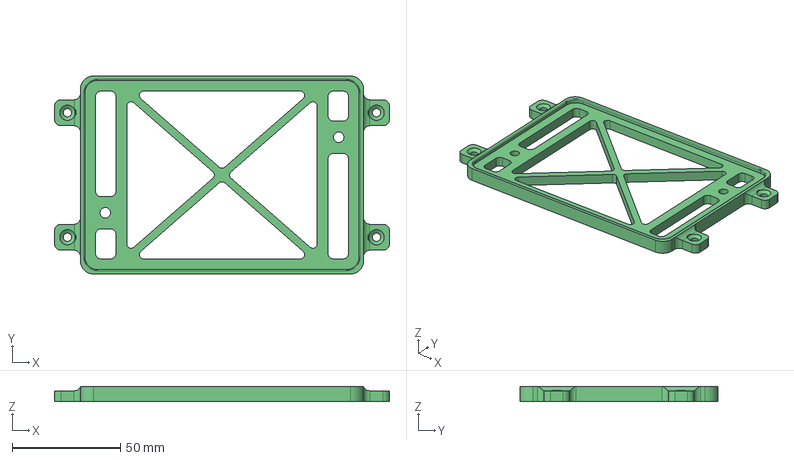
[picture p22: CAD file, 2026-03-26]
cad_files/Motor Setup/Motor Controller/Motor Controller Foundation.step
154.9 x 91.6 x 7.00 mm

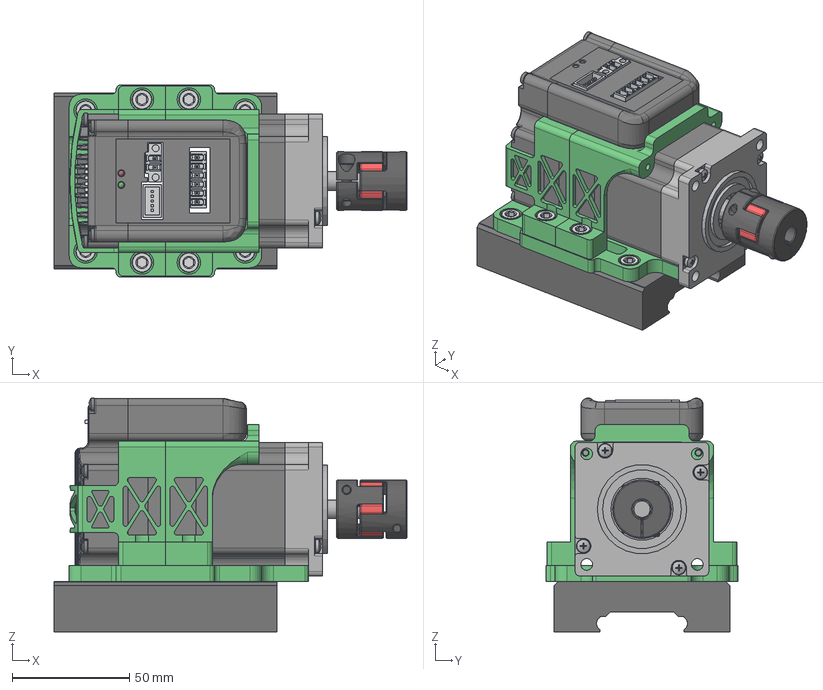
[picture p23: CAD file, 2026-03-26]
cad_files/Motor Setup/Rotational Motor (RM) Setup/RM Carriage Setup (Goalie).step
150.5 x 82.0 x 99.7 mm
¸´¼þ hk.stp^HPVB45-200
91290A123_Alloy Steel Socket Head Screw x 2
91292A124_18-8 Stainless Steel Socket Head Screw x 8
CT_1
QG_1
FPCB_2
CONNECTOR_3_81MM6PIN_MALE_2
CONNECTOR_3_81MMCLOSED2PIN_MALE
DPCB_1
BOMA_1
CPCB_2
LS22_2 x 6
LS10_2 x 2
LS2_5_2 x 3
front end cover
GB__T818-2000______________M3__ x 4
GB__T276-94__________6000-2Z
GB__T848-2002______A__3__0__5 x 4
PRODUCT_14681
GB__T276-94__________608-2Z
PRODUCT_22216
21 shaft-1
LGR RM Carriage Bracket (Goalie)
LGR RM Back Holder (Goalie)
LGR RM Front Holder (Goalie)
Sprzęgło D25 L30.iam

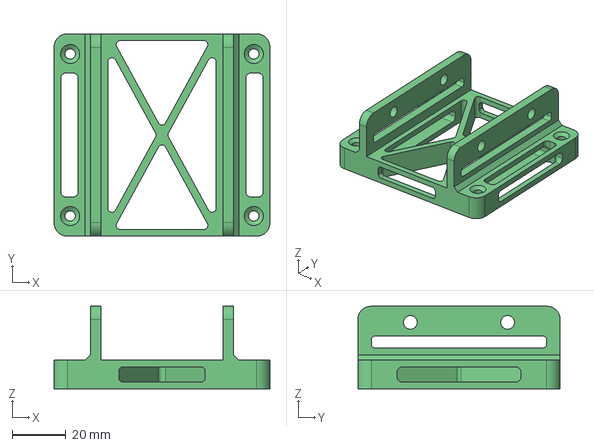
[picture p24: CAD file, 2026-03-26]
cad_files/Motor Setup/Translational Motor (TM) Setup/Linear Guide Rail (LGR) Components/LGR Foundation.step
80.0 x 75.0 x 30.6 mm

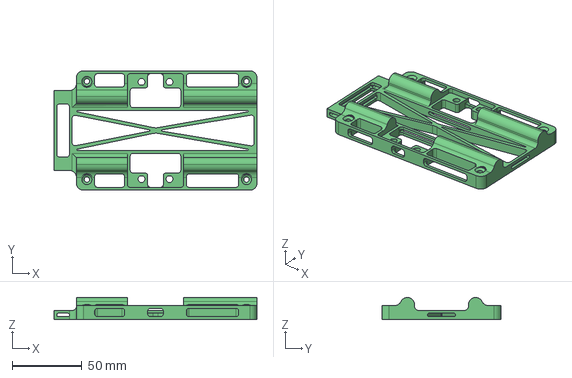
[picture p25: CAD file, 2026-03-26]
cad_files/Motor Setup/Translational Motor (TM) Setup/TM Foundation.step
145.0 x 85.2 x 15.8 mm

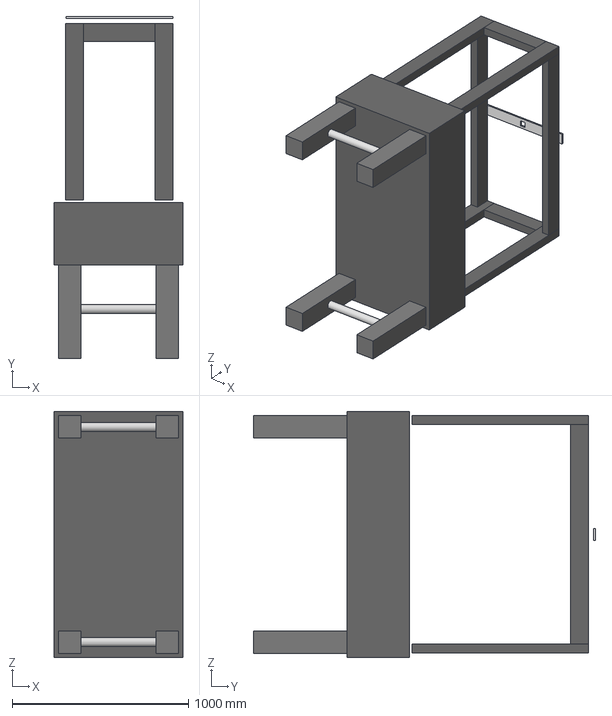
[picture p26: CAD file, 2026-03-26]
cad_files/Overhead Stand/Assembly Drafts/Camera stand.step
730.0 x 1938.5 x 1397.0 mm

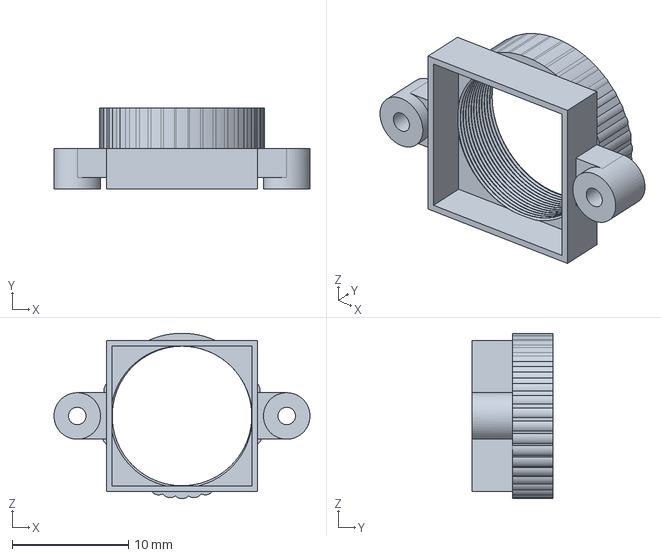
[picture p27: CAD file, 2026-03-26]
cad_files/Overhead Stand/Camera Holder/Arducam OV9782/OV9782 Base.step
22.0 x 7.00 x 14.2 mm

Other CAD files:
cad_files/Motor Setup/Full Motor Build (Goalie).step
cad_files/Overhead Stand/Camera Holder/Camera Holder/Camera Holder Drafts/Make one of these.step
cad_files/Overhead Stand/Camera Holder/Camera Holder/Camera Holder Middle.step
cad_files/Overhead Stand/Camera Stand.step
cad_files/Microcontroller/Pi Active Cooler.f3d
cad_files/Microcontroller/Raspberry Pi 5.f3d
cad_files/Microcontroller/Raspberry Pi Case.f3d
cad_files/Microcontroller/Raspberry Pi Case.step
cad_files/Motor Setup/Full Motor Build (Defensemen).f3z
cad_files/Motor Setup/Full Motor Build (Goalie).f3z
cad_files/Motor Setup/Jaw Coupler.f3d
cad_files/Motor Setup/Jaw Coupler.step
cad_files/Motor Setup/Motor Controller/CLCR-4-13.f3d
cad_files/Motor Setup/Motor Controller/Motor Controller Assembly.f3z
cad_files/Motor Setup/Motor Controller/Motor Controller Foundation.f3d
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

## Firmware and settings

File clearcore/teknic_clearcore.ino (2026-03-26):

#include "ClearCore.h"
#include <stdint.h>
#include <stdlib.h>

#define ioPort ConnectorUsb
#define ioPortBaudRate 115200
#define MAX_RPM 1000
#define PULSES_PER_REV 2000
#define COOLDOWN_MS 100

// one revolution is ~7.6cm
#define PULSES_PER_CM 263.157894737
#define MAX_GOAL_MOVE_CM 23

// container for the char stream to be read-in
#define IN_BUFFER_LEN 32

// motor connectors
MotorDriver *const motors[MOTOR_CON_CNT] = {
  &ConnectorM0, &ConnectorM1, &ConnectorM2, &ConnectorM3
};

void moveDistance(int m_index, int distance);
void goalieKick(int m_index);

uint32_t lastMotorAction[MOTOR_CON_CNT] = {0,0,0,0};

// Must be less than or equal to clock speed of 100KHz
// Velocity/PPR = RPM
uint32_t velocityLimit  = (MAX_RPM * PULSES_PER_REV) / 60; // pulses/sec
uint32_t accelerationLimit = 300000; // pulses/sec^2

uint8_t cmd_running[4] = {0};

void setup()
{

  ioPort.Mode(Connector::USB_CDC);  
  ioPort.Speed(ioPortBaudRate);
  ioPort.PortOpen();
  while (!ioPort);

  MotorMgr.MotorInputClocking(MotorManager::CLOCK_RATE_LOW);

  // Sets all motor connectors into step and direction mode.
  MotorMgr.MotorModeSet(MotorManager::MOTOR_ALL,
                        Connector::CPM_MODE_STEP_AND_DIR);

  // These lines may be uncommented to invert the output signals of the 
  // Enable, Direction, and HLFB lines. Some motors may have input polarities 
  // that are inverted from the ClearCore's polarity.
  //motor.PolarityInvertSDEnable(true);
  //motor.PolarityInvertSDDirection(true);
  //motor.PolarityInvertSDHlfb(true);

  for(int m = 0; m < MOTOR_CON_CNT; m++)
  {

    // Sets the maximum velocity for each move
    motors[m]->VelMax(velocityLimit);


    // Set the maximum acceleration for each move
    motors[m]->AccelMax(accelerationLimit);

    motors[m]->EnableRequest(true);
  }

}

void loop()
{

  uint32_t i;

  while(1)
  {

    ioPort.SendLine("IDLE... WAITING FOR S");

    char start_input[IN_BUFFER_LEN+1];
    i = 0;
    while(i<IN_BUFFER_LEN)
    {
      if(ioPort.CharPeek() == -1) continue;
      char c = ioPort.CharGet();
      if(c == '\n') break;
      start_input[i++] = c;
    }
    start_input[i] = '\0';

    if(start_input[0] == 'S')
    {
      break;
    }

    delay(250);
  }

  ioPort.SendLine("STARTING");

  char input[IN_BUFFER_LEN+1];
  int cmd_idx = 0;
  uint8_t cmd_ready = 0;

  while(1)
  {

    cmd_ready = 0;
    cmd_idx = 0;

    if(ioPort.CharPeek() != -1)
    {
      while(cmd_idx<IN_BUFFER_LEN) 
      {
        if(ioPort.CharPeek() == -1) continue; 
        char c = ioPort.CharGet(); 
        if(c == '\n') break; 
        input[cmd_idx++] = c; 
      }
      input[cmd_idx] = '\0';
      cmd_ready = 1;
    }

    if(cmd_ready && input[0] == 'Z')
    {
      ioPort.SendLine("STOPPING");
      break;
    }

    // GOALIE KICK
    if(cmd_running[0])
    {
      uint32_t curr_time = Milliseconds();
      if(motors[0]->StepsComplete() && curr_time - lastMotorAction[0] > COOLDOWN_MS)
      {
        cmd_running[0] = 0;
        ioPort.SendLine("ad");
      }
    }
    else if(cmd_ready)
    {
      if(cmd_idx > 0 && input[0] == 'a')
      {
        motors[0]->Move(-PULSES_PER_REV);
        ioPort.SendLine("PERFORMING GOALIE KICK");
        cmd_running[0] = 1;
        uint32_t curr_time = Milliseconds();
        lastMotorAction[0] = curr_time;
      }
    }

    // GOALIE MOVE
    if(cmd_running[1])
    {
      uint32_t curr_time = Milliseconds();
      if(motors[1]->StepsComplete() && curr_time - lastMotorAction[1] > COOLDOWN_MS)
      {
        cmd_running[1] = 0;
        ioPort.SendLine("bd");
      }
    }
    else if(cmd_ready)
    {
      if(cmd_idx > 3 && input[0] == 'b' && isdigit(input[1]) && isdigit(input[2]) && isdigit(input[3]))
      {
        int cm_move = atoi(&input[2]);
        int dir = input[1] - '0';
        if(cm_move < MAX_GOAL_MOVE_CM)
        {
          int pulse_move = cm_move * PULSES_PER_CM;
          pulse_move = dir ? -pulse_move : pulse_move;
          motors[1]->Move(pulse_move);
          ioPort.Send("MOVING GOALIE ");
          ioPort.Send(cm_move);
          ioPort.Send(" cm, direction ");
          ioPort.SendLine(dir);
          cmd_running[1] = 1;
          uint32_t curr_time = Milliseconds();
          lastMotorAction[1] = curr_time;
        }
      }
    }

    // DEF KICK
    if(cmd_running[3])
    {
      uint32_t curr_time = Milliseconds();
      if(motors[3]->StepsComplete() && curr_time - lastMotorAction[3] > COOLDOWN_MS)
      {
        cmd_running[3] = 0;
        ioPort.SendLine("cd");
      }
    }
    else if(cmd_ready)
    {
      if(cmd_idx > 0 && input[0] == 'c')
      {
        motors[3]->Move(-PULSES_PER_REV);
        ioPort.SendLine("PERFORMING DEFENDER KICK");
        cmd_running[3] = 1;
        uint32_t curr_time = Milliseconds();
        lastMotorAction[3] = curr_time;
      }
    }

    // DEF MOVE
    if(cmd_running[2])
    {
      uint32_t curr_time = Milliseconds();
      if(motors[2]->StepsComplete() && curr_time - lastMotorAction[2] > COOLDOWN_MS)
      {
        cmd_running[2] = 0;
        ioPort.SendLine("dd");
      }
    }
    else if(cmd_ready)
    {
      if(cmd_idx > 3 && input[0] == 'd' && isdigit(input[1]) && isdigit(input[2]) && isdigit(input[3]))
      {
        int cm_move = atoi(&input[2]);
        int dir = input[1] - '0';
        if(cm_move < MAX_GOAL_MOVE_CM)
        {
          int pulse_move = cm_move * PULSES_PER_CM;
          pulse_move = dir ? -pulse_move : pulse_move;
          motors[2]->Move(pulse_move);
          ioPort.Send("MOVING DEFENDER ");
          ioPort.Send(cm_move);
          ioPort.Send(" cm, direction ");
          ioPort.SendLine(dir);
          cmd_running[2] = 1;
          uint32_t curr_time = Milliseconds();
          lastMotorAction[2] = curr_time;
        }
      }
    }


  }
}

  /**

    switch(input[0])
    {
      case 'a':
      {
        // Perform goalie kick
        goalieKick(0);
        break;
      }

      case 'b':
      {
        // Perform goalie move, motion given in cm
        if(i > 3 && isdigit(input[1]) && isdigit(input[2]) && isdigit(input[3]))
        {
          int cm_move = atoi(&input[2]);
          int dir = input[1] - '0';
          if(cm_move > MAX_GOAL_MOVE_CM) break;
          int pulse_move = cm_move * PULSES_PER_CM;
          pulse_move = dir ? -pulse_move : pulse_move;
          moveDistance(1, pulse_move);
        }

        break;
      }

      case 'c':
      {
        // Perform defender kick
        goalieKick(3);
        break;
      }

      case 'd':
      {
        // Perform defender move, motion given in cm
        if(i > 3 && isdigit(input[1]) && isdigit(input[2]) && isdigit(input[3]))
        {
          int cm_move = atoi(&input[2]);
          int dir = input[1] - '0';
          if(cm_move > MAX_GOAL_MOVE_CM) break;
          int pulse_move = cm_move * PULSES_PER_CM;
          pulse_move = dir ? -pulse_move : pulse_move;
          moveDistance(2, pulse_move);
        }
        
        break;
      }

      case 'Z':
      {
        stop = true;
      }

      default:
        break;
    }

    if(stop == true)
    {
      ioPort.SendLine("STOPPING");
      break;
    }
  }
}

void goalieKick(int m_index)
{
  MotorDriver *motor = motors[m_index];
  uint32_t curr_time = Milliseconds();

  if(motor->StepsComplete() && curr_time - lastMotorAction[m_index] > COOLDOWN_MS)
  {
    motor->Move(-PULSES_PER_REV);
    lastMotorAction[m_index] = curr_time;
    ioPort.Send("PERFORMED KICK ON MOTOR ");
    ioPort.SendLine(m_index);
  }
  else
  {
    ioPort.SendLine("REJECTED");
  }
}

void moveDistance(int m_index, int distance)
{
  MotorDriver *motor = motors[m_index];
  uint32_t curr_time = Milliseconds();

  if(motor->StepsComplete() && curr_time - lastMotorAction[m_index] > COOLDOWN_MS)
  {
    ioPort.Send("MOVING MOTOR ");
    ioPort.Send(m_index);
    ioPort.Send(" ");
    ioPort.Send(distance);
    ioPort.SendLine(" PULSES");
    motor->Move(distance);
    lastMotorAction[m_index] = curr_time;
  }
  else
  {
    ioPort.SendLine("REJECTED");
    delay(500);
  }
}
*/

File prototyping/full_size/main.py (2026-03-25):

import collections
import math
import cv2
import numpy as np
import signal
import time
from math import sin, cos, atan
from multiprocessing import Pool, Queue, Array
import threading

from arucos import process_aruco, get_perspective_matrix
from motor_control import init_control, kick

availability = Array('b', 4)
for i in range(4):
	availability[i] = True

def receive(ser):
	global availability
	while True:
		try:
			if ser.in_waiting > 0:
				# Read the line until a \n is found
				response = ser.readline()

				# Decode bytes back into a string and strip whitespace
				decoded_response = response.decode('utf-8').strip()
				if decoded_response.startswith("MOVING GOALIE"):
					availability[1] = False
					decoded_response += f' {time.time()}'
				else:
					if decoded_response == 'ad':
						availability[0] = True
					elif decoded_response == 'bd':
						availability[1] = True
					elif decoded_response == 'cd':
						availability[2] = True
					elif decoded_response == 'dd':
						availability[3] = True
				# print(f"Received: {decoded_response}")
		except serial.SerialException as e:
			print(f"Error: Could not open serial port {SERIAL_PORT}. Is it plugged in?")
			print(f"Details: {e}")
		except Exception as e:
			print(f"An unexpected error occurred: {e}")

# --------------------
# Ball color thresholds
# --------------------
lower_orange = np.array([15 / 2, 255 * .35, 10])
upper_orange = np.array([45 / 2, 255 * .65, 255])

# lower_pink = np.array([340 / 2, 255 * .05, 0])
# upper_pink = np.array([380 / 2, 255 * .4, 255])
# partition_1 = 35.71
# partition_2 = 64.29
# gap = 28.57

colors_low = [np.array([0, 255 * .3, 70]), np.array([350 / 2, 255 * .3, 70])]
colors_high = [np.array([10 / 2, 255 * .95, 255]), np.array([180, 255 * .95, 255])]

# location_start = [0, 100, 300, 500]
# location_end = [25, 125, 325, 525]
# num_foosmen = [1, 2, 5, 3]
# avg_pos = [-100, -100, -100, -100]
location_start = [0, 110]
location_end = [25, 130]
num_foosmen = [1, 2]
avg_pos = [-100, -100]

# First rod: 1 foosman, limited in movement unlike other rods 68 21
# min_first = 30.88
# max_first = 69.12
min_first = 38
max_first = 62

min_second = 35
max_second = 65

# Second rod: 2 foosmen
# Third rod: 5 foosmen
# Fourth rod: 3 foosmen
# partitions = [(100.0), (50.0, 100.0), (20.0, 40.0, 60.0, 80.0, 100.0), (33.333, 66.667, 100.0)]
# gaps = [100.0, 50.0, 20.0, 33.333]
partitions = [(100.0), (50.0, 100.0)]
gaps = [100.0, 48.0]

# --------------------
# ArUco setup
# --------------------
NUM_ARUCOS = 12
rod_ids = [(4, 5), (6, 7), (8, 9), (10, 11)] # from the automatic rod closest to own goal to the farthest
rod_centers = {}
W, H = 800, 600             # warped output size


KICK_THRESHOLD = 5
LENGTH_THRESHOLD = 25

# --------------------
# Multiprocessing setup
# --------------------
def init_pool(d_b):
    global detection_buffer
    detection_buffer = d_b

def detect_object(frame):
    detection_buffer.put(frame)

history = collections.deque(maxlen=5)

# --------------------
# Serial connection
# --------------------
ser = None

import numpy as np

def clip_line_to_frame(x1, y1, x2, y2):
    dx = x2 - x1
    dy = y2 - y1
    points = []

    # Avoid division by zero
    if abs(dx) > 1e-6:
        # left edge (x=0)
        t = -x1 / dx
        y = y1 + t*dy
        if 0 <= y <= H-1:
            points.append((0 - 20, int(round(y))))
        # right edge (x=W-1)
        t = (W-1 - x1) / dx
        y = y1 + t*dy
        if 0 <= y <= H-1:
            points.append((W-1 - 20, int(round(y))))

    if abs(dy) > 1e-6:
        # top edge (y=0)
        t = -y1 / dy
        x = x1 + t*dx
        if 0 <= x <= W-1:
            points.append((int(round(x)) - 20, 0))
        # bottom edge (y=H-1)
        t = (H-1 - y1) / dy
        x = x1 + t*dx
        if 0 <= x <= W-1:
            points.append((int(round(x)) - 20, H-1))

    # We expect 2 valid intersections
    if len(points) >= 2:
        return points[0], points[1]
    else:
        return None, None

def percent_along_line(rod_pt1, rod_pt2, intersection):
    p1 = np.array(rod_pt1, dtype=float)
    p2 = np.array(rod_pt2, dtype=float)
    pi = np.array(intersection, dtype=float)

    rod_vec = p2 - p1
    inter_vec = pi - p1

    rod_len = np.linalg.norm(rod_vec)
    if rod_len < 1e-6:
        return 0.0  # degenerate case
    
    # projection of inter_vec onto rod_vec
    t = np.dot(inter_vec, rod_vec) / (rod_len**2)

    # percentage along the rod
    return t * 100.0

def point_on_line(rod_pt1, rod_pt2, percent):
    """
    rod_pt1s[i], rod_pt2s[i]: (x,y) endpoints of rod line (clipped to frame)
    percent: float in [0,100], percentage along rod_pt1→rod_pt2
    """
    p1 = np.array(rod_pt1, dtype=float)
    p2 = np.array(rod_pt2, dtype=float)
    t = percent / 100.0
    return tuple((p1 + t*(p2 - p1)).astype(int))
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

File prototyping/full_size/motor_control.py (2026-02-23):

import serial
import time

# CONFIGURATION
# Replace with the port you found in Step 2
SERIAL_PORT = '/dev/ttyACM0'  
# Replace with the baud rate specified in your motor controller manual
BAUD_RATE = 115200 

def init_control():
	try:
		# 1. Open the Serial Connection
		# timeout=1 means "wait 1 second for a message, then give up" so we don't freeze
		ser = serial.Serial(SERIAL_PORT, BAUD_RATE, timeout=1)
		
		# Wait a moment for the connection to settle
		while not ser.is_open:
			time.sleep(2) 
		print(f"Connected to {SERIAL_PORT} at {BAUD_RATE} baud.")
		command = "S\n" 
		ser.write(command.encode('utf-8'))
		print(f"Sent: {command.strip()}")
		return ser
	except serial.SerialException as e:
		print(f"Error: Could not open serial port {SERIAL_PORT}. Is it plugged in?")
		print(f"Details: {e}")
		return None
	except Exception as e:
		print(f"An unexpected error occurred: {e}")
		return None

def kick(ser, com):
	try:
		# 2. SENDING A MESSAGE
		# Motor controllers often expect a command ending in a newline (\n) or carriage return (\r)
		# The .encode('utf-8') converts your string into bytes
		command = f"{com}\n" 
		ser.write(command.encode('utf-8'))
		print(f"Sent: {command.strip()}")

		# 4. Close the connection when done
		# ser.close()
	except serial.SerialException as e:
		print(f"Error: Could not open serial port {SERIAL_PORT}. Is it plugged in?")
		print(f"Details: {e}")
		return None
	except Exception as e:
		print(f"An unexpected error occurred: {e}")
		return None

def receive(ser):
	while True:
		try:
			if ser.in_waiting > 0:
				# Read the line until a \n is found
				response = ser.readline()
				
				# Decode bytes back into a string and strip whitespace
				decoded_response = response.decode('utf-8').strip()
				print(f"Received: {decoded_response}")
		except serial.SerialException as e:
			print(f"Error: Could not open serial port {SERIAL_PORT}. Is it plugged in?")
			print(f"Details: {e}")
		except Exception as e:
			print(f"An unexpected error occurred: {e}")

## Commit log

2025-09-03 Extend direction vector to find intersection point with axis of rod closest to goal, which is now detected using pink post-its wrapped around it
2025-09-10 Replaced motorized rod tracking with Aruco, and detects which of the 3 foosmen to focus on interception point
2025-09-29 Added kick simulation by highlighting rod
2025-10-16 Adding STL file for PSU cover
    [PSU Cover v60.stl]
2025-11-17 Added camera testing code and started refactoring of code for full size table
2026-02-23 Feb 23 Update
    Contains 1 rod lateral movement and rotational reaction, debug camera feed view disabled
2026-03-26 Adding Teknic ClearCore Controller code for the motors
2026-03-26 Moving documents around
    [PSU Cover v60.stl]
2026-03-26 Adding all Fusion 360 files in .f3d and .step
    [Arducam OV9782 Camera Board.f3z, Arducam OV9782 Camera Board.step, CLCR-4-13.f3d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]
